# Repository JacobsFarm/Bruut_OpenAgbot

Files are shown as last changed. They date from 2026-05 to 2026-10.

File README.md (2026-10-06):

# Bruut_OpenAgbot
Project for making the Bruut_OpenAgbot 

Follow along the project on youtube: https://www.youtube.com/@opensource_agbot/videos
Visit the website for more information https://jacobsfarm.github.io/Bruut_openagbot_website/ 
Go for the implements to the special repo https://github.com/JacobsFarm/Bruut_OpenAgbot_Implements

newest configuration the 2WD: with AB line driving
DJI_0523
dasgewagergsdg

This repo contains all the code information and code for the Agbot bruut Project 
The first runs for the prototype wil be used code in Python, C++ and the front end bases on svelte
later the project wil immigrate to ROS 2 and Floxglove 

## openscad project
New cad designs after testing in the Field, stronger and more realistic designs and even more oppertunity for extensions

animation_drive_turn
animatie_ridderzuringfrees
animation_strip_ground_following

**4 wheeldrive designs** with 4 electric driven hubmotors
Schermafbeelding 2026-05-24 135653
Schermafbeelding 2026-05-24 135643
Schermafbeelding 2026-05-24 135613
Schermafbeelding 2026-05-24 135552

**2 wheeldrive designs** difference is 2 wheel casters in the back
Schermafbeelding 2026-05-24 223704
Schermafbeelding 2026-05-24 223727

## AB line driving
Schermafbeelding 2026-08-24 190629
DJI_0523

## Options 
making taskcards of the detection of diseases / birdnests or Sprayed weed
Schermafbeelding 2026-04-26 231133

## AB-line missions

Autonomous field work runs on AB lines. You measure two points with the RTK:
**A = the bottom-left corner** of the field and **B = the top-left corner**.
Together they set the direction and the length of the swaths.

Build the mission with a single script:

```bash
python Single_script_code/AB_mission_maker.py
```

Set the field name, the two points, the work width and the number of swaths at
the top of the script. It writes the mission into `data/ab_line.json` and draws
a preview: `ab_missie.jpg` (field sketch in metres), `ab_missie_gps.jpg` (same mission in lat/lon) and `ab_missie.html` (interactive satellite map)
so you can check the headlands before driving.

The script plans a **skip pass** order: on the way out it skips a swath every
time (0, 2, 4, 6) and on the way back it fills the gaps (7, 5, 3, 1). The side
step at almost every headland turn is then twice the work width, which is
exactly what a four-wheeler needs - a half circle of twice the minimum turning
radius fits. Only at the turning point of the pattern (6 -> 7) do two swaths sit
next to each other; there the robot drives an omega turn instead.

At the end of a swath the robot keeps going straight for `kopakker_extra_m`
(2 m by default) into the headland before it turns. The turn is built so that it
ends at exactly the same distance along the line as where it started, so after
the turn the robot has that same 2 m of straight run-in to settle dead straight
on the new line before the crop begins.

Pick the field in the web interface under **Landbouw** and press start.

> [!WARNING]
> **Disclaimer: use at your own risk**
> - This is an experimental prototype under active development, not a finished or certified product.
> - All software and designs are open source (AGPL-3.0) and provided **"as is"**, without warranty of any kind. The makers and contributors are not liable for any damage, injury or loss resulting from their use (see sections 15 and 16 of the license).
> - Autonomous machines can behave unexpectedly, for example by driving into a ditch or water. Always supervise the robot, test at low speed, use a physical emergency stop, an RC failsafe and a geofence, and keep people and animals at a safe distance.
> - You are responsible for complying with local laws and safety regulations. Do not use the robot on public roads.

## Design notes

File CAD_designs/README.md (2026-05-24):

# Bruut_OpenAgbot
Project for making the Bruut_OpenAgbot 

Gemini_Generated_Image_ldpsodldpsodldps(1)

## openscad project
Volume 2 ( redesign (better alignments and stronger realistic design  
Schermafbeelding 2026-05-24 135552
Schermafbeelding 2026-05-24 135643
Schermafbeelding 2026-05-24 135653


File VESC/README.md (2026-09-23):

# VESC instellen — Bruut OpenAgbot

Twee **VESC Classic 100V** sturen elk een **Quinder 8" 48V 550W naafmotor** aan,
gevoed uit een **EGO 56 V-accu**, aangestuurd door de Jetson over **CAN**.

| | |
|---|---|
| Motor | Quinder 8" 48V 550W · art. 10101025 · 2× |
| Controller | VESC Classic 100V · 2× |
| Accu | EGO 56 V, 5 Ah = **14S2P** · ~252 Wh |
| Vervangt | Quinder DC-controller 10301059 + Arduino/MCP4728-DAC |
| Aansturing | Jetson · CAN 500 kbit/s · ID 0 (links) en 1 (rechts) |
| Topsnelheid | 6 km/h = 3 900 ERPM · **nooit boven 7 km/h** |

Dit bestand is de **werkvolgorde en de instellingen**. De volledige onderbouwing —
waarom CAN en geen UART, hoe het thermisch model werkt, de vermogensbalans bij
remmen — staat in [README_DEV.md](README_DEV.md).

> De VESC Tool is gratis. Een kleine donatie aan het VESC-project helpt hen
> verder met de software waar jij op meelift.

---

## Voordat er spanning op staat

* **Wiel vrij van de grond.** Bok eronder, vóórdat de accu erop gaat.
* **Precharge.** XT90-S of voorlaadweerstand — dit board heeft flinke condensatoren.
* **Quinder-controller volledig los van de fasedraden**, maar **niet doorknippen**:
  hij is je terugvaloptie én je referentiemeting.
* **Fase = 2,5 mm², hall = 0,14 mm².** Blauw, groen en geel komen twee keer voor
  in de motorkabel. Verwissel je ze, dan blaas je de hall-sensoren op.
* **Nooit + en − verwisselen.** Dat sloopt de halls, en die zitten in een
  IP66-behuizing die je niet openmaakt.
* **Zekering 30 A**, en controleer de **DC**-waarde — auto-steekzekeringen zijn
  vaak op 32 V DC gespecificeerd en jij zit tot ~58 V.
* Eén board tegelijk via USB. CAN komt pas in stap 12.

**Begin met `Read Motor Configuration`.** Wat de VESC Tool zonder uitlezen toont
zijn defaults van een vreemd hardwareprofiel — dan bewerk je een configuratie die
nergens bestaat. Controleer je limieten ook **na elke firmware-flash**; een flash
kan ze resetten.

---

## De instellingen

Elk scherm afsluiten met **Write Motor Configuration**. De tool schrijft niets uit
zichzelf weg — en schrijft álle velden, ook die je niet aanraakte.

### Motor Settings → General

| Veld | Waarde | |
|---|---|---|
| Motor Type | **FOC** | Vol koppel vanaf stilstand, stil bij kruipsnelheid, bruikbare stroommeting |
| Invert Motor Direction | **False** | Beslis dit in stap 11. De motoren zitten gespiegeld, dus één board krijgt `True` |

Zet de vlag hier en niet in de software: dan draaien telemetrie, tacho en het
teken van de regenstroom mee. Wissel **geen fasedraden** — dat maakt de
uitgemeten halltabel ongeldig.

### Motor Settings → Sensors

| Veld | Waarde | |
|---|---|---|
| Sensor Port Mode | **Hall Sensors** | Ons hele bereik is 0–3 900 ERPM; de sensorloze waarnemer wordt pas ergens rond 1 000–2 000 ERPM betrouwbaar. Sensorloos betekent elke start op een helling blind |

Encoder- en Sin/Cos-velden ongemoeid laten: die worden niet gelezen.

### Motor Settings → Current

| Veld | Default | Waarde | |
|---|---|---|---|
| Motor Current Max | 60 A | **15 A** | Continu belastbaar is ~9 A. 15 i.p.v. 20 A scheelt 44 % warmte (I²) en kost 25 % piekkoppel |
| Motor Current Max Brake | −60 A | **−10 A** | Remmen belast dezelfde wikkeling, vaak ná een klim |
| Absolute Maximum Current | 150 A | **30 A** | Noodrem, geen regellimiet. 2× bedrijf, ruim onder wat 2,5 mm² aankan |
| Slow ABS Current Limit | False | **False** | Houdt die trip snel; True maakt er een trage softwarelimiet van |
| Battery Current Max | 99 A | **20 A** | Motorspec max output. Wordt in de praktijk nooit bereikt: de motorlimiet bindt eerder |
| Battery Current Max Regen | −60 A | **−3 A** | Zie *Remmen* hieronder — dit getal hangt aan de accu, niet aan de motor |

Overige velden (current scales, input current map, DRV8301) laten staan.

### Motor Settings → Voltage

| Veld | Default | Waarde | |
|---|---|---|---|
| Battery Voltage Cutoff Start | 10 V | **42,0 V** | Motorspec zegt 41 ±1 V, én het is 3,00 V/cel op 14S. Twee redeneringen, één antwoord |
| Battery Voltage Cutoff End | 8 V | **40,0 V** | Dit is de **enige** onderspanningsbeveiliging die er is — zie *De accu* |
| Battery Voltage Regen Cutoff Start | 1000 V | **56,0 V** | Vanaf hier bouwt de VESC de teruglevering zelf af. Het bijpassende snelheidsplafond in de software is nog niet gebouwd — zie README_DEV |
| Battery Voltage Regen Cutoff End | 1100 V | **57,5 V** | = gemiddeld 4,11 V/cel. Bewust laag: er is geen celbewaking die ingrijpt |
| Battery Filter Constant | 45 | *laten* | Niet scherper zetten: onder belasting zakt de spanning kort in, en zonder filter gaat je cutoff af op elke stroompiek |

### Motor Settings → RPM

| Veld | Default | Waarde | |
|---|---|---|---|
| Max ERPM | 100 000 | **3 900** | 6 km/h. Absoluut plafond 4 569 (7 km/h) — daar nooit overheen |
| Max ERPM Reverse | −100 000 | **−3 900** | Open punt: halveren naar −1 950 (3 km/h) is verdedigbaar op 500 kg |
| ERPM Limit Start | 80 % | *laten* | Knijpt vanaf 3 120 geleidelijk af i.p.v. tegen een muur |

### Motor Settings → Wattage

**Beide velden laten staan** (1 500 000 W = begrenzer uit). De stroomlimieten
begrenzen het vermogen al; een wattlimiet ernaast is een tweede begrenzer voor
dezelfde grootheid, die zich anders gaat gedragen naarmate het pak leegloopt.

### Motor Settings → Temperature

| Veld | Waarde | |
|---|---|---|
| Motor Temperature Sensor Type | **Disabled** | De Quinder-sensor is **geen thermistor**: hij geeft actief spanning af (~4,8 V koud, 1,09 V bij 105 °C, 0,68 V bij 110 °C). Tegen een 10k pull-up levert dat geen meting op |
| MOSFET Temp Cutoff | 85 / 100 °C *laten* | Echte sensor op het board. De enige thermische meting zonder aanname eronder |

Het paarse draadje gaat via een deler ÷2 naar **AD2**, waar een Lisp-script de
drempels bewaakt. Zolang dat script niet draait, is het thermisch model in
`motor_logic.py` je enige motorbescherming — en dat draait op berekende, nog niet
geijkte startwaarden.

### Motor Settings → BMS

**BMS Type → `Disabled`.** Dit scherm is voor een VESC-BMS die celspanningen over
CAN doorgeeft. Een EGO-pak spreekt dat protocol niet. Laat je het op *VESC BMS*
staan, dan staat er een begrenzer scherp die wacht op gegevens die nooit komen.

### Motor Settings → Advanced

| Veld | Default | Waarde | |
|---|---|---|---|
| **Maximum Input Voltage** | **57,0 V** | **65,0 V** | Een vol 14S-pak is 58,8 V. Op 57 V krijg je een `OVER_VOLTAGE`-fout zodra de accu vol van de lader komt — en een fout zet de motor in één klap uit |
| Maximum Duty Cycle | 95 % | *laten* | Niet naar 100 %: die marge heeft de eindtrap nodig om fasestroom te meten |
| Fault Stop Time | 500 ms | *laten* | **Niet** de CAN-timeout — die staat in App Settings en is toevallig ook 500 ms |
| Additional Faults | uit | **uit laten** | Zie hieronder |

> `57,0 V` is een 12S-default. Staat dat er ná `Read Motor Configuration` nog
> steeds, dan is het uitlezen niet gelukt. Op een echt 100 V-board hoort hier al
> 90 V of meer te staan — laat het dan staan.

**Waarom `Overspeed` uit blijft:** een fout zet de motor uit, en deze machine
heeft geen mechanische rem. Rolt hij een helling af en gaat daardoor over de
limiet, dan haalt die fout precies weg wat hem nog tegenhield. Runaway-detectie
zit in de software, waar de reactie een *gestuurde* actie kan zijn.

### Motor Settings → FOC · detectie

Halls aangesloten, wiel vrij, limieten hierboven al weggeschreven. Draai de
detectie en lees de uitkomst één keer goed:

* De zes middelste getallen van de halltabel horen **zes verschillende** waarden
  te zijn. Twee dezelfde = een sensor die niet schakelt.
* **0 en 7 horen er niet in te staan** — dat is alle drie laag of alle drie hoog:
  dode sensor, gebroken draad of geen voeding.
* Noteer R, L en flux linkage in het [Meetblad](#meetblad).

Klopt de tabel niet, dan is dat bedrading — niet iets wat je met een instelling
repareert.

### Motor Settings → PID Controllers

**Speed PID min ERPM → 150.** Standaard staat dit veel hoger; daarmee regelt hij
onder ~1,4 km/h niet.

### App Settings · per board

| Parameter | Links | Rechts | |
|---|---|---|---|
| VESC ID | **0** | **1** | Onderste byte van elk CAN-adres; moet uniek zijn |
| CAN Baud Rate | 500k | 500k | |
| CAN Status Message Mode | 1 – 5 | 1 – 5 | Levert eRPM, stroom, duty, temperaturen, tacho en `v_in` zonder pollen |
| CAN Status Rate | 50 Hz | 50 Hz | |
| Multiple VESCs Over CAN | **uit** | **uit** | Die functie spiegelt één gascommando naar alle VESC's — aan betekent: niet kunnen sturen |
| Timeout | 500 ms | 500 ms | **De belangrijkste failsafe** |
| Timeout Brake Current | 0 A | 0 A | Uitrollen bij verlies van commando, niet remmen op een onbekende situatie |
| App to Use | UART / CAN | UART / CAN | Niet ADC — dat houdt AD2 vrij voor het temperatuursignaal |

**De timeout is je beste beveiliging omdat hij niet van onze software afhangt.**
Stopt de Jetson met sturen, dan zetten beide VESC's zichzelf na 500 ms uit — ook
als deze codebase niet meer draait. Daarom zendt de regellus in
`vehicle_controller.py` onafgebroken op 50 Hz, ook als er niets verandert.

**Toon dat één keer aan:** laat een wiel draaien en trek de CAN-kabel eruit. Hij
hoort binnen een halve seconde uit te vallen.

---

## Remmen

**Er zit nergens een mechanische rem.** Wat de machine tegenhoudt is uitsluitend
wat de VESC elektrisch doet, en dat kan alleen als de accu de energie aanneemt.

Een regenlimiet is **geen kraan die stroom omleidt** — het is een randvoorwaarde
voor de regelaar. Mag er niets naar het pak, dan verlaagt de VESC de fasestroom:
hij remt minder hard. De energie wordt niet omgeleid, hij wordt niet onttrokken,
en de machine rolt door. Bij stilstand kun je wél vol houden (snelheid nul, dus
geen mechanisch vermogen — alles wordt warmte).

| Regen per VESC | Totaal | Houdt bij 6 km/h | Houdt bij 3 km/h |
|---|---|---|---|
| **−3 A** | 6 A · 312 W | **~4 %** | ~8 % |
| −5 A | 10 A · 520 W | ~6 % | ~13 % |
| −10 A | 20 A · 1 040 W | ~13 % | ~25 % |

Vuistregel bij 6 km/h: elke ampère teruglevering koopt ~0,6 % helling.

**Waarom −3 A en niet meer:** laadstroom hoort afgezet tegen het aantal cellen
*parallel*. Het 10 Ah-pak is 14S4P van 2,5 Ah-cellen (Samsung INR18650-25R,
4 A snellaadstroom), dus een 5 Ah-pak is **14S2P**. Met −3 A per VESC zit je op
3 A per cel; met −5 A op 5 A per cel, boven spec.

| Pak | Opbouw | Regen per VESC |
|---|---|---|
| 2,5 Ah | 14S1P | −1,5 A |
| **5,0 Ah** | **14S2P** | **−3 A** |
| 7,5 Ah | 14S3P | −4 A |
| 10 / 12 Ah | 14S4P | −5 A |

> **Een te lage regenlimiet maakt niets kapot.** De VESC maakt die stroom
> eenvoudigweg niet. De keuze voor een mechanische rem is een veiligheids- en
> functievraag, geen vraag over het beschermen van onderdelen.

**Waar het wél misgaat:** slepen of rollen met de controller uit. Dan regelt
niemand en komt de generatorspanning via de body-diodes hoe dan ook op de bus.
Met accu erop wordt die geklemd; zonder accu laden de condensatoren op tot niets
het meer tegenhoudt. **Sleep nooit met de hoofdschakelaar uit, en precharge ook
na een sleepbeurt.**

**En stilstaand een helling houden op stroom kookt de motor** — vol koppel, geen
luchtstroom. Daarvoor is de stall-detectie.

---

## De accu

Wat de teardowns en de DIY-gemeenschap over EGO 56 V-pakken melden, en wat het
voor ons betekent:

* **De plus- en minklem gaan rechtstreeks naar de cellenstring, om de elektronica
  heen.** De hoofdstroom loopt niet door de BMS.
* **Er zit geen afschakel-MOSFET in.** De BMS beveiligt door over de `D`-pin
  tegen het *gereedschap* te zeggen dat het moet uitschakelen — en een VESC is
  geen EGO-gereedschap.

| | Gevolg |
|---|---|
| Afkoppelen tijdens remmen | **Kan niet** — er is geen schakelaar om te openen |
| Overladen via regen | **Niemand vangt het af.** Geen cutoff, geen laadstroomlimiet, geen celbewaking |
| Onderspanning per cel | Niet beschermd. Onze 42,0 V is de enige grens |

Alles wat dit pak tijdens teruglevering beschermt is dus een instelling in onze
VESC. Daarom ligt de regenband bewust laag.

**Nog te meten:** wat een vol pak werkelijk aanwijst. EGO geeft 50,4 V nominaal
op en de cellen zijn 4,2 V-types, dus 58,8 V is de theoretische bovengrens — maar
de naam "56 V" volgt de conventie waarin het merkgetal 14 × 4,0 V is. Eén
multimetermeting na het laden beslist de hele taperband.

**En meet wat de stock-controller doet.** Die heeft op déze machine met dít pak
al geremd. Stroomtang om de plusdraad op een helling die hij nog houdt: meer dan
6 A betekent dat onze −3 A conservatief is.

---

## Bedrading

### Motor → VESC

Kabel 3 × 2,5 mm² + 8 × 0,14 mm², 200 mm — je hebt een verlengboom nodig.

| Draad | Ø | Functie | Naar |
|---|---|---|---|
| Blauw / Groen / Geel | 2,5 | Motorfase A / B / C | Fase-uitgangen |
| Rood / Zwart | 0,14 | Hall + / − | Sensorconnector +5V / GND |
| Blauw / Groen / Geel | 0,14 | Hall A / B / C | H1 / H2 / H3 |
| Wit | 0,14 | Toerentalpuls (6/omw) | **Niet aansluiten** — de VESC telt via de halls, tienmaal fijner |
| Paars | 0,14 | Temperatuursignaal | Via deler ÷2 → IO-connector AD2 |

De hall-volgorde is niet kritisch: de detectie meet de tabel uit.

```
IO-CONNECTOR                        SENSORCONNECTOR
paars (temp) ──[10k]──┬── AD2       rood  ── +5V
                      │             zwart ── GND
                    [10k]           blauw ── H1
                      │             groen ── H2
                      ├──[100nF]    geel  ── H3
                      └── GND
```

### CAN

JST-GH 4-polig: `1 = 5V uit`, `2 = CANH`, `3 = CANL`, `4 = GND`.

* **Verbind pin 1 niet tussen de twee VESC's.** Dat is bij allebei een *uitgang*.
  Tussen de boards lopen alleen CANH, CANL en GND.
* **Eén CAN-connector per board**, dus drie knopen betekent een T-split of een
  verdeelprintje — doorlussen kan niet.
* **120 Ω alleen aan de twee fysieke uiteinden.** Meet met de accu los tussen
  CANH en CANL: je hoort **~60 Ω** te zien. 40 Ω = drie terminators, 120 Ω = één.
* Twisted pair plus een aparte GND-draad. Vertrouw niet op het chassis, en houd
  de bundel weg bij de fasedraden.

**Aan de Jetson-kant: een geïsoleerde socketcan-adapter.** De productpagina moet
*SocketCAN*, *gs_usb* of *candleLight* noemen en hij moet als `can0` verschijnen
— bijvoorbeeld een InnoMaker USB2CAN (ISO1050) of CANable Pro. Een goedkope
CH340-UART-brug is **niet** bruikbaar: die verschijnt als `/dev/ttyUSB0` en kan
geen willekeurige 29-bits ID's sturen. Je hebt er **één** nodig, niet twee — CAN
is een bus.

```bash
ip link | grep can        # can0 -> goed
sudo ip link set can0 up type can bitrate 500000 restart-ms 100
candump can0              # statusframes van beide ID's op 50 Hz
```

Zonder `restart-ms` blijft de interface dood na één bus-off. `setup/can0.service`
doet dit bij elke boot.

---

## Rekenwaarden

Herbereken deze als je van band, tandwielkast, massa of accu wisselt.

| Grootheid | Waarde | Afleiding |
|---|---|---|
| Bandomtrek | 1,277 m | 16" buitenmaat × π |
| Poolparen · overbrenging | 10 · 5:1 | |
| **ERPM per wiel-RPM** | **× 50** | 5 × 10 |
| 6 km/h | 3 917 ERPM | afgerond naar 3 900 |
| 7 km/h — nooit hoger | 4 569 ERPM | grens DaviLot |
| Tellen per wielomwenteling | 300 | odometrie: 4,26 mm per tel |
| Continu belastbaar | 9,0 A · 75 RPM | ≈ 5,7 km/h |
| Massa (aslast) | 500 kg | motorspec |
| Accu vol (theoretisch) | 58,8 V | 14S × 4,2 V — **meet dit na** |

---

## Beveiligingslagen

| # | Waar | Wat |
|---|---|---|
| 1 | VESC | Motor Current Max 15 A — voorkomt de oorzaak |
| 2 | Software | Stall-detectie op stroom en toerental |
| 3 | Software | Thermisch model op gemeten stroom (ongeijkt) |
| 4 | VESC | **Timeout 500 ms** — werkt ook als onze software dood is |
| 5 | Hardware | Zekering 30 A DC |
| 6 | VESC | Lisp-script op AD2 met de echte motorsensor |

---

## Meetblad

Invullen tijdens het in bedrijf stellen. Dit is de verantwoording van wat er
werkelijk in de boards staat.

| | Links (ID 0) | Rechts (ID 1) |
|---|---|---|
| Datum · serienummer · firmware | | |
| Halltabel (8 getallen) | | |
| Motor R (mΩ) · L (µH) · flux (mWb) | | |
| Invert Motor Direction | | |
| Vol commando → gemeten ERPM | | |
| Maximum Input Voltage zoals uitgelezen | | |
| Paarse draad koud gemeten (V) | | |
| Timeout aangetoond (datum) | | |
| Geëxporteerd configbestand | | |

Eenmalig, niet per board:

| | Waarde |
|---|---|
| Pakspanning vol, direct na laden | |
| Nemen de klemmen stroom aan? (labvoeding ~0,5 A) | |
| Regenstroom stock Quinder-controller (stroomtang) | |
| Neemt het pak −3 A regen aan? | |

---

## Tot slot

**Schrijf `vesc_mcconf_openagbot_bruut_500_watt_hubmotor.xml` niet naar een
board.** Dat is het oude profiel van ánder materiaal; de motorparameters zijn
niet van deze motor. De werkwijze is andersom: uitlezen, limieten invoeren,
detectie draaien, en het resultaat **exporteren naar deze map**. Dát wordt het
echte configbestand.

Verdieping — waarom CAN en geen UART, waarom geen Arduino in het stuurpad, de
vermogensbalans bij remmen, het Lisp-script, de openstaande vragen:
[README_DEV.md](README_DEV.md).

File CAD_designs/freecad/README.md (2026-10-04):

# Bruut OpenAgbot - FreeCAD model

FreeCAD 1.1 versie van het ontwerp: 2 vaste hubmotorwielen achter, 2 sturende hubmotorwielen voor met elk een
stappenmotor (NEMA34 + 5:1 planeetkast) erboven. Gebouwd uit de OpenSCAD-bestanden, de foto's in `Design real life/`
en de stappenmotorplaat `parts/PLOATIE 2.STP`.

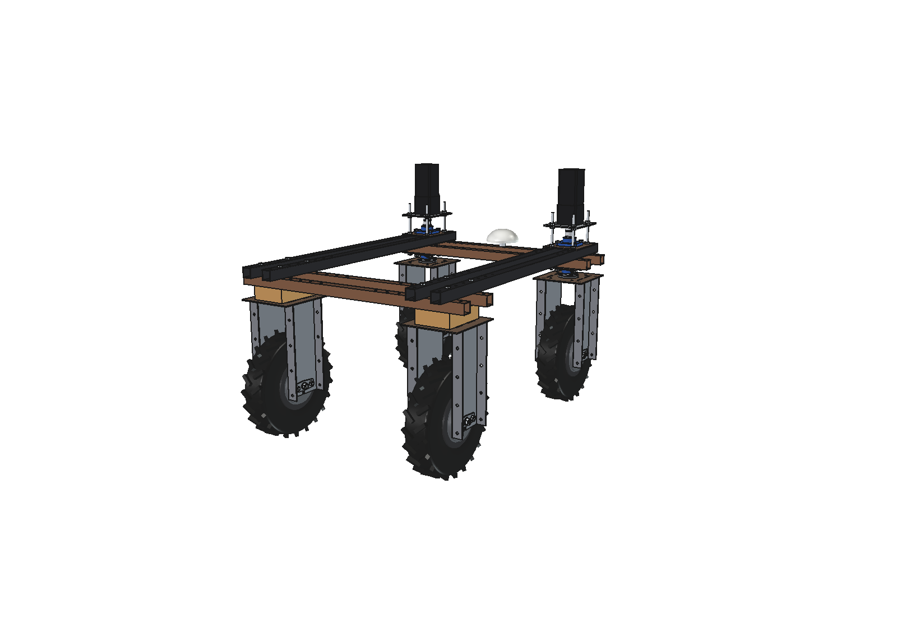
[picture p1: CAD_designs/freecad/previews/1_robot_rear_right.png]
achteraanzicht

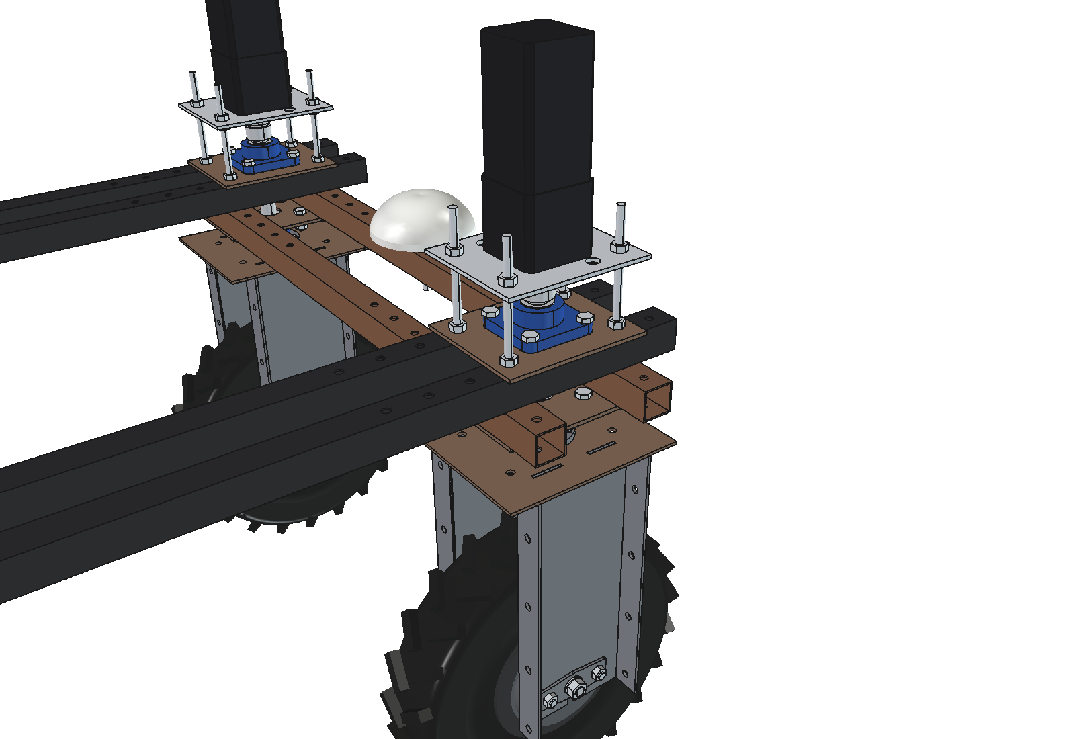
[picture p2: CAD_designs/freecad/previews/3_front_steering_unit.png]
stuurkop


## Bestanden

| Bestand | Inhoud |
| --- | --- |
| `Bruut_OpenAgbot.FCStd` | het model (openen in FreeCAD) |
| `agbot_params.py` | alle maten, zelfde namen en waarden als `config/parameters.scad`, plus de nieuwe stuurparameters |
| `agbot_parts.py` | een functie per fysiek onderdeel (zoals `parts/*.scad`) |
| `build_agbot.py` | zet de onderdelen in de boomstructuur, kleurt ze en slaat op |
| `run_in_freecad.py` | start-macro: open in FreeCAD en voer uit (F6), dan wordt het model opnieuw gegenereerd |
| `animate_agbot.py` | animatie rijden en draaien: kinematica, live afspelen in FreeCAD, frames renderen |
| `make_gif.py` | zet de gerenderde frames om naar een GIF (Pillow) |
| `previews/` | afbeeldingen (isometrisch, bovenaanzicht, zijaanzicht, achteraanzicht, stuurkop) en `animation_drive_turn.gif` |

Opnieuw genereren overschrijft het open document `Bruut_OpenAgbot` en `Bruut_OpenAgbot.FCStd`.
Pas maten aan in `agbot_params.py`, nooit in het FCStd-bestand zelf (die onderdelen zijn niet parametrisch).

## Assen

x = rechts, y = rijrichting (voor = +y), z = omhoog, grond = z 0. Wielmiddens op x = ±375, y = ±500, as op z = 215.
In FreeCAD's "Front"-weergave kijk je dus naar de achterkant van de robot; "Rear" toont de voorkant.

## Boomstructuur

```
Bruut_OpenAgbot_robot
  chassis_frame                  4 onderste balken (chassis_beam_1), 4 bovenste balken (chassis_beam_2), GNSS-antenne
  wheel_unit_rear_left / right   hubmotorwiel, wielbeugel, houten blok, boutwerk
  wheel_unit_front_left / right  stuurkop: lagerplaten, 2 flenslagers, stappenmotorplaat, stappenmotor, draadstangen
    steered_part_front_*         alles dat meedraait met het stuur: wiel, beugel, stuuras, koppeling
  optional_frame_cover_NOT_ON_PHOTOS   main_base_plate, upright_wall, protection_cover (verborgen)
```

## Sturen

Draai `steered_part_front_left` / `steered_part_front_right` (Placement, rotatie om z; + = naar links), of in de
Python-console:

```python
import build_agbot
build_agbot.set_steering(30, 22)
```

Binnenwiel scherper dan buitenwiel (Ackermann), zie ook `setup/information/steppermotor_information.json`.

## Animatie

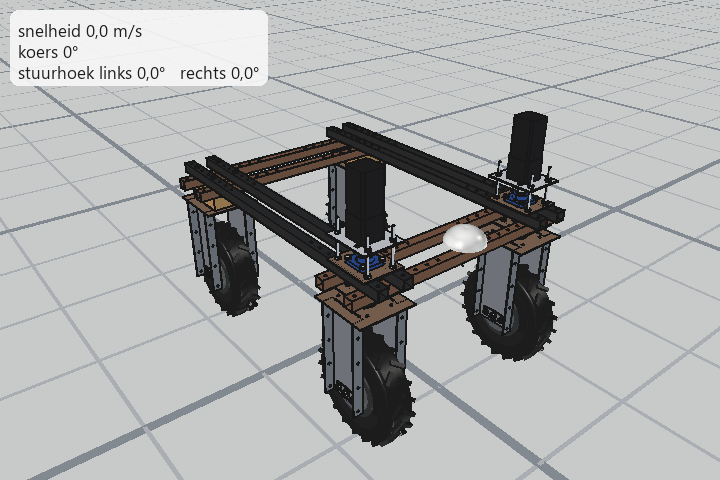
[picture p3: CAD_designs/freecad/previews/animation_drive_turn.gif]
rijden en draaien


De robot rijdt 1,2 m rechtuit (0 naar 1 m/s), stuurt naar links, draait 90° en rijdt weer rechtuit tot stilstand.
Kinematica: fietsmodel op het midden van de achteras. Elk voorwiel krijgt zijn eigen stuurhoek (Ackermann: bij 25°
middenhoek staat het binnenwiel op 29,5° en het buitenwiel op 21,6°, draaicirkel 2,1 m), alle wielen rollen zonder
slip af en de stuurmotoren draaien met 35°/s. Snelheid, hoeken en afstanden staan bovenaan `animate_agbot.py`.

Live afspelen in FreeCAD (het model `Bruut_OpenAgbot` moet open staan, de camera volgt de robot):

```python
import animate_agbot
animate_agbot.play()
animate_agbot.stop()
```

De GIF opnieuw maken (frames renderen in FreeCAD, daarna in een gewone terminal):

```python
animate_agbot.render_all(r"C:\temp\frames")
```

```
python make_gif.py C:\temp\frames previews\animation_drive_turn.gif 15
```

## Wat komt waar vandaan

**Exact uit OpenSCAD** (volume en afmetingen vergeleken met een OpenSCAD-STL-export: verschil < 0,01 %):
`bracket_top_plate`, `bracket_side_plate` (gebogen uitvoering), `axle_bracket`, `chassis_beam_1`, `chassis_beam_2`,
`main_base_plate`, `upright_wall`, `protection_cover`, positie van de wielen en de balken.
`PLOATIE 2` is parametrisch nagebouwd en heeft hetzelfde volume als het STEP-bestand (131 249,2 mm3).

**Afgeleid uit de foto's, maten geschat (aanpassen in `agbot_params.py`):**
- stuurkop: draaipuntflens op de top plate (4x M8, 50 x 50), stuuras O25, twee flenslagers (blauw, UCF205-maten) in
  platen onder en boven het frame, koppeling, 4 draadstangen M10 op het 150 x 100 patroon;
- stappenmotor + planeetkast (90 x 90 x 85 en 86 x 86 x 150), top van de motor op 1032 mm;
- `steering_gap` = 55 mm tussen top plate en onderste balken; achter vult een houten blok die ruimte;
- positie van de GNSS-antenne: midden, op de voorste dwarsbalk.

**Vervangers** (de STL's `hubmotor_quinder*.stl` en `tire_4.8_4.00-8.stl` staan niet in de repo): band 430 x 100 met
tractorprofiel, velg 8", motorhuis O160 x 140. Alle vier de wielen zijn gelijk, ook de voorste (op de foto's zitten
daar nog andere banden).

**Niet gemodelleerd:** kabels, trekhaak, label op de motor, afschuiningen op moeren.

## Aandachtspunten

- De optionele frame-onderdelen (uit `chassis_frame_asm.scad`) staan niet op de foto's en botsen met de rechter
  stuurkop (stappenmotor op x = 375, y = 500). Daarom verborgen.
- In OpenSCAD liggen de onderste balken 2 mm boven de top plate (`bracket_top_z` als plaatmidden). Hier liggen ze
  tegen de plaat of het houten blok.
- Controle op interferentie: geen overlap tussen de 80 zichtbare onderdelen.

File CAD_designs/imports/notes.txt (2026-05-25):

In this directory can you place yout STL files for importing them into your designs

The used STL models can be retrieved from the importer of yout hubmotor, i use Quinder 48v hubmotors
The used STL models for the casterwheels are from a wheelbarrow wheel and can be downloaded from the next link https://grabcad.com/library/wheelbarrow-wheel-4-80-4-00-8-1

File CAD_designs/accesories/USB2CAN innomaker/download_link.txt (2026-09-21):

To download een ready to use Innomaker USB2CAN module case.
  
https://makerworld.com/en/models/28738-innomaker-usb2can-module-case?utm_source=gemini#profileId-2465581

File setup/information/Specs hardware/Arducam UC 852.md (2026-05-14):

Overview

Arducam B0385 is a new member of Arducam's USB camera family. It's a 1MP, based on the 1/4" color global shutter OV9782 image sensor, UVC compliant, low distortion USB 2.0 camera.

No longer be anxious about installing the driver! The native UVC drivers of Windows, Linux and Mac shall be compatible with this camera so that it does not require extra drivers to be installed.

The global shutter sensor's excellent low-light sensitivity makes it shoot crisp sharp and accurate complete color images even for high-speed moving objects.

Features

    Based on 1MP color global shutter sensor OV9782, assembled with a 70°(H) low distortion M12 lens with 650nm IR filter, sensitive to Visible Light.
    Global Shutter: Shoot high-speed moving objects in crisp sharp images. Avoid the rolling artifacts to get a much more accurate complete picture than the rolling shutter cameras. Reserved external trigger ports, support trigger via external signal.
    Resolution: 1MP 1280H x 800V; Frame Rates: MJPG 100fps@1280 x 800/720p/800 x 600/640 x 480/320 x 240; YUY2 10fps@1280 x 800/1280 x 720.
    Plug&Play: UVC-compliant, just connect the camera to a PC computer, laptop, Android device, or Raspberry Pi with the USB cable without extra drivers to be installed.
    Applications: The sensor's excellent low-light sensitivity and the low distortion lens allow it to perform better in any application that needs gesture and eye tracking, iris and physiognomy recognition, depth, and motion detection.

Applications

Iris and face recognition

Astrophotography

Gesture and eye tracking

Depth and motion detection

Home video surveillance system

......
Specs

Camera

- Sensor: 1/4” OV9782

- Resolution: 1MP 1280 x 800

- Data Format: MJPG/YUY2

- Frame Rate: MJPG 100fps@1280 x 800/720p/800 x 600/640 x 480/320 x 240; YUY2 10fps@1280 x 800/1280 x 720.

Lens

- Field of View (FOV): 70 degrees (H)

- Lens Mount: M12

- IR Sensitivity: IR filter, sensitive to Visible Light

- Focusing Range: 3.3ft (1M) to infinity

Functionality and Compatibility

- Adjustable parameter: Exposure/ White Balance

- System Compatibility: Windows, Linux, Mac, and OS with UVC driver

Power

- Power Supply: USB powered 5V

- Working Current: MAX 200mA

Physical

- Operating Temp.: -4°F~158°F (-20°C~+70°C).

- Dimension: 38mmx38mm (Hole pitch compatible with 34mmx34mm, 28x28mm)

- Cable Length: 3.3ft (1M)

1.1 Supported resolutions and frame rates¶
MJPG    1280×800@100fps
MJPG    800×600@100fps
MJPG    640×480@100fps
MJPG    320×240@100fps
YUV2    1280×800@10fps
YUV2    1280×720@10fps

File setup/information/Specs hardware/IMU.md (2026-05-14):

Virtual reality is populair, maar je zou geen honderden dollars moeten uitgeven om de technologie erachter te krijgen. Gelukkig is dit waar de VR IMU Breakout binnenkomt. De kern is CEVA's BNO086, een gecombineerd triaxiale versnellingsmeter/gyroscoop/magnetometer-pakketsysteem (SiP) in 32-bits ARM © Cortex™M0 +. De BNO086 Inertial Measurement Unit (IMU) produceert nauwkeurige rotatievectorkoppen, ideaal voor VR-en andere koerstoepassingen, met een statische rotatiefout van 2 graden of minder. De VR IMU is precies waar we op hebben gewacht; Alle sensorgegevens worden samengevoegd en gecorrigeerd tot zinvolle, nauwkeurige IMU-informatie. Het is perfect voor elk project dat richting of beweging moet voelen.

Het IMU-splitbord wordt ook geleverd met twee I2C Qwiic-connectoren om de verbinding met het miniatuur QFN-pakket iets gemakkelijker te maken. Het maakt deel uit van het Qwiic-verbindingssysteem, dus u hoeft niet te lassen om erachter te komen hoe de dingen zijn georiënteerd. Als u echter liever een breadboard gebruikt, hebben we nog steeds 0,1 "uit elkaar geplaatste pinnen.

De BNO080 is ontworpen om te worden gebruikt in Android-telefoons en kan alle berekeningen aan die nodig zijn voor een virtual reality-bril met alleen de telefoon. Voor BNO080 EOL biedt CEVA een plug-in alternatief voor BNO086 met verbeterde functies (14-bits accelerometerfusie, minder inactief vermogen en interactieve kalibratie). De sensor is zeer krachtig en wordt geleverd met een complexe interface. Dankzij de jumper op het bord kun je kiezen tussen twee verschillende I2C-adressen. Niettemin, als I2C niet uw favoriete communicatieoptie is, kunnen de sensoren communiceren via SPI en UART! We hebben ook een I2C-based bibliotheek geschreven die rotatievectoren biedt (de metingen die de meeste mensen van een IMU willen), versnelling, gyroscoop-en magnetometermetingen, staptellingen, en activiteitsclassifiers (zoals fietsen).

Het is een ecosysteem van I2C-sensoren, actuatoren, schilden en kabels die prototyping sneller en minder foutgevoelig maken. Alle QWIIC-compatibele kaarten gebruiken de gemeenschappelijke 1mm pitch, 4-pins JST-connector. Dit vermindert de vereiste PCB-ruimte, en de gepolariseerde verbinding betekent dat u het niet verkeerd kunt ophangen.

Bedrijfsspanning

2.4v tot 3.6v

Meestal 3,3 V via Qwiic-kabel

I2C (standaard): tot 400kHz

SPI: tot 3MHz

UART: 3 mbps

Rotatievector

Dynamische fout: 3,5 °

Statische fout: 2.0 °

Spelrotatie vector

Dynamische fout: 2,5 °

Statische fout: 1,5 °

Dynamische cursusdrift: 0,5 °/ min

Geomagnetische rotatie vector

Dynamische rotatiefout: 4,5 °

Statische rotatiefout: 3,0 °

Zwaartekracht Hoekfout: 1,5 °

Lineaire versnellingsnauwkeurigheid: 0,35 m/s2

Accelerometer nauwkeurigheid: 0,3 m/s2

Nauwkeurigheid gyroscoop: 3.1 °/ s

Magnetometer nauwkeurigheid: 1.4 & micro;T

2 Qwiic-verbindingspoorten

I2C adres: 0x4B (standaard), 0x4A

I2C pull-up weerstand (2.2kΩ)

Vermogen LED

Springschot

Vermogen LED

I2C pull-up weerstand

Adreselectie

Protocol selectie 0

Protocol optie 1

Bordgrootte: 1.0in. X 1.2. (25,4mm x 30,48mm)

Gewicht: 3g.

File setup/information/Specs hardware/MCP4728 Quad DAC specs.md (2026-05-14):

The MCP4728 is a compact module featuring four 12-bit Digital-to-Analog Converters (DACs), ideal for precise voltage setting requirements. This module is compatible with STEMMA QT and Qwiic connectors for easy "plug-and-play" integration via I2C.

## Key Features

* **Quad 12-bit Outputs:** Four independent buffered voltage output DACs.
* **Non-Volatile Memory (EEPROM):** Ability to store DAC settings and I2C address bits in internal EEPROM. Saved settings are automatically loaded as defaults upon power-up.
* **Flexible Reference Voltage:** Choose between the input supply voltage (VCC) or an internal reference of 2.048V.
* **Adjustable Gain:** When using the internal reference, you can select 1X or 2X gain.
* **Fast Response:** Typical settling time of 6 μs.
* **I2C Interface:** Fully controllable via I2C with a default address of `0x60`.

## Technical Specifications

| Feature | Specification |
| :--- | :--- |
| **Resolution** | 12-bit  |
| **Operating Voltage** | 2.7 V to 5.5 V  |
| **Settling Time** | 6 μs (typical) |
| **Differential Non-Linearity (DNL)** | ±0.2 LSB (typical) |
| **Default I2C Address** | 0x60  |

## Voltage Output Ranges

The output voltage range depends on the selected reference voltage (Vref) and gain settings:

* **Internal VREF (2.048V):**
    * **Gain = 1:** 0.000V to 2.048V[.
    * **Gain = 2:** 0.000V to 4.096V (Ideal for ~5V applications).
* **External VREF (VDD/VCC):**
    * 0.000V to VDD (Allows matching the input voltage range, e.g., 3.3V or 5V)

## Pinout Overview

The module features several connection points for integration:
* **VCC:** Power supply (2.7V - 5.5V).
* **GND:** Ground.
* **SCL/SDA:** I2C Clock and Data lines.
* **VA, VB, VC, VD:** The four DAC output channels.
* **RDY:** Ready pin.
* **LDAC:** Latch DAC Synchronization pin.
"""

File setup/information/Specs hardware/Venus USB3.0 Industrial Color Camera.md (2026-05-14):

{
  "product": {
    "name": "Venus USB3.0 Industrial Color Camera",
    "part_number": "VEN-161-61U3C-M01",
    "manufacturer": "Daheng Imaging",
    "description": "Compact industrial USB3 Vision camera with Sony IMX296 global shutter sensor."
  },
  "housing_options": [
    {
      "model": "VEN-161-61U3C-M06",
      "housing": "No housing",
      "dimensions_mm": "32.5x32.5x8.1",
      "weight_g": 7
    },
    {
      "model": "VEN-161-61U3C-M05",
      "housing": "M12",
      "dimensions_mm": "35x35x15.1",
      "weight_g": 32
    },
    {
      "model": "VEN-161-61U3C-M01",
      "housing": "CS-mount",
      "dimensions_mm": "35x35x15.8",
      "weight_g": 31
    },
    {
      "model": "VEN-161-61U3C-M01 + 5mm extension ring",
      "housing": "C-Mount",
      "dimensions_mm": "35x35x20.8",
      "weight_g": 34
    }
  ],
  "lens_mount_options": {
    "supported_mounts": ["M12", "CS-mount", "C-Mount"],
    "notes": "M12 lenses can be used directly with the M12 version or with the CS-mount version using a C-to-M12 adapter."
  },
  "specifications": {
    "interface": "USB3 Vision",
    "resolution": {
      "width": 1440,
      "height": 1080
    },
    "megapixel": 2,
    "frame_rate_fps": 61,
    "sensor": {
      "model": "IMX296",
      "size": "1/2.9\"",
      "pixel_size_um": 3.45,
      "type": "Color",
      "shutter_type": "Global Shutter"
    },
    "shutter_time": {
      "min": "52us",
      "max": "1s"
    },
    "adc_bit_depth": 10,
    "pixel_bit_depth": [8, 10],
    "digital_gain_db": {
      "min": 0,
      "max": 24
    },
    "pixel_data_format": [
      "Bayer RG8",
      "Bayer RG10"
    ],
    "synchronization": [
      "Hardware trigger",
      "Software trigger"
    ],
    "io": {
      "input": 1,
      "gpio": 1
    },
    "operating_conditions": {
      "temperature_c": {
        "min": 0,
        "max": 45
      },
      "humidity_percent": {
        "min": 10,
        "max": 80
      }
    },
    "mount": ["S", "C"],
    "dimensions_mm": {
      "cs_m12": "35x35x15.2",
      "no_housing": "32.5x32.5x8.1"
    },
    "sdk_support": [
      "Windows",
      "Linux",
      "Android"
    ],
    "power_consumption": "<2.7W@5V",
    "weight_g": 32,
    "certifications": [
      "RoHS",
      "CE",
      "FCC",
      "USB3 Vision",
      "GenICam"
    ]
  },
  "industrial_color_camera_info": {
    "technology": "Bayer pattern",
    "advantages": [
      "Excellent image quality",
      "Larger and more light-sensitive pixels than webcams and security cameras"
    ],
    "limitations": [
      "Less sharp than monochrome cameras",
      "Lower light sensitivity due to RGB filters"
    ],
    "light_sensitivity_compensation": [
      "Increase ambient light",
      "Increase gain",
      "Increase shutter speed/exposure time",
      "Use a more light-sensitive sensor",
      "Use a more light-sensitive lens"
    ]
  },
  "warranty_and_lifecycle": {
    "annual_production": 100000,
    "certification": "TÜV Rheinland",
    "warranty_years": 3,
    "minimum_product_lifecycle_years": 7
  }
}

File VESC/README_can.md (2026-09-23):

# CAN wiring: Innomaker USB2CAN → VESC Classic 100V

Innomaker USB2CAN Module (bare board, DB9 male, micro-USB) on a Jetson, talking to a VESC Classic 100V over CAN at 500 kbit/s.

> **Never connect Pin 1 to 5 volt on the VSEC, its a 5 V output on both connectors.** The Innomaker is USB-powered, the VESC is battery-powered. Linking those two pins puts two supplies against each other, will blow up the controller and computer.

## Connect these 3 wires

```text
INNOMAKER DB9 (male)         VESC CLASSIC  CAN, 4-pin JST-GH 1.25 mm

pin 7  CAN_H   ───────────── pin 2  CANH    ┐ twisted pair
pin 2  CAN_L   ───────────── pin 3  CANL    ┘
pin 3  CAN_GND ───────────── pin 4  GND

pin 1  5V      ─ leave open ─ pin 1  +5V
DB9 pins 4, 5, 6, 8, 9: NC
```
Innomaker USB2CAN diagram

| Innomaker DB9 | Function | VESC CAN | Function |
|---|---|---|---|
| pin 7 | CAN_H, dominant high | pin 2 | CANH, ±60 V |
| pin 2 | CAN_L, dominant low | pin 3 | CANL, ±60 V |
| pin 3 | CAN_GND | pin 4 | GND, 1 A |
| pin 1 | 5 V out — only live if R9 is fitted | pin 1 | +5 V out, 1 A — **do not connect** |

- **Run CAN_H and CAN_L as a twisted pair**, roughly one turn per 2 cm.
- **The ground wire is not optional.** The Innomaker's transceiver is isolated (ISO1050); without CAN_GND it has no reference against the VESC and you get random error frames.
- Keep the CAN cable away from the phase wires — crossing at right angles is fine, running parallel is not. Alongside the motor, use shielded cable and ground the shield at one end only.
- Wire colours are free; nothing in the VESC depends on them.

## No open end

A CAN bus is a straight line with 120 Ω between CAN_H and CAN_L at **each** end. A wire left dangling reflects the signal and produces bit errors as soon as speed or length goes up.

Adding more VESCs later: daisy-chain wheel to wheel, stubs under 30 cm, and only the **two outermost** nodes get a resistor. With the Jetson at one end, the last VESC in the chain is the other.

## Termination

| Side | What to do |
|---|---|
| Innomaker USB2CAN Module | 120 Ω is on the board. Fit the jumper next to the DB9 — manual p. 11, *Enable 120 Ohm Resistor*. It usually ships disabled. |
| VESC Classic 100V | No termination on the board (not in the datasheet, confirmed by measurement). Solder a plain 120 Ω ¼ W across pins 2 and 3 of the JST-GH connector, or use a T-splitter with a resistor. |

Measure across CAN_H and CAN_L with the battery disconnected and USB unplugged:

| Reading | Meaning |
|---|---|
| open / very high | no termination at all |
| ≈ 120 Ω | one end terminated, the other still missing |
| ≈ 60 Ω | both ends terminated — this is what you want |

Also check CAN_H→GND and CAN_L→GND: both must be high impedance. If not, there's a solder bridge in the DB9.

## Bring it up on the Jetson

The module is a gs_usb SocketCAN device. VESC defaults to 500 kbit/s.

**On the Jetson Orin Nano (JetPack 6) the adapter is `can1`, not `can0`.** `can0` is the Orin's own CAN controller (mttcan). JetPack 6 also ships without `gs_usb`, so the driver is built with DKMS. The full steps are in [setup/information/innomaker_usb2can_jetson_setup.json](../setup/information/innomaker_usb2can_jetson_setup.json). The backend uses `vesc.can_channel` = `can1` from `data/config.json`.

```bash
sudo ip link set can1 down
sudo ip link set can1 type can bitrate 500000 loopback off
sudo ip link set can1 up
candump can1
```

`restart-ms` is not supported by gs_usb — `ip link set can1 up` fails with *"Device doesn't support restart from Bus Off"* if you pass it. After a bus-off, take the interface down and up again with the commands above.

## VESC Tool

*App Settings → General*:

| Setting | Value |
|---|---|
| CAN Baud Rate | `CAN_BAUD_500K` |
| CAN Mode | `VESC` |
| VESC ID | `1`, `2`, `3`, `4` — unique per controller |
| Can Status Rate 1 | `50` Hz, tick **Status 1** |
| Can Status Rate 2 | `5` Hz, tick **Status 4** and **Status 5** |

Status 1 at 50 Hz is the control loop; the rest belongs on the slow group. Four VESCs × 5 messages × 50 Hz is a quarter of the bus; Status 1 fast and the rest at 5 Hz is about 6%.

> **Write with ↑A, not ↑M.** VESC Tool keeps motor and app configuration separate, each with its own toolbar buttons. Writing App Settings with the motor-config button (↑M) silently discards them — the screen keeps showing your ticks while the controller never received them. Verify with ↓A: if the boxes survive a read-back, it landed.

## What comes over the bus

Extended IDs, built as `command << 8 | VESC ID`. For VESC ID 1:

| ID | Command | Contents |
|---|---|---|
| `0x901` | 9, STATUS | eRPM, motor current, duty — 50 Hz |
| `0x1001` | 16, STATUS_4 | temperatures, motor current |
| `0x1B01` | 27, STATUS_5 | input voltage, tacho |
| `0x3901` | 57, NOTIFY_BOOT | payload is the ASCII hardware name, sent once at power-up |

Status 1, all big-endian:

| Bytes | Value |
|---|---|
| 0–3 | eRPM, int32 |
| 4–5 | motor current, int16, ÷10 → A |
| 6–7 | duty cycle, int16, ÷1000 → fraction |

The Quinder has 20 poles = 10 pole pairs, so wheel RPM = eRPM ÷ 10. At standstill expect `00 00 00 00 00 00 FF FC`: zero rpm, zero current, −0.4% duty of noise around zero.

A useful check that does not depend on any status setting — ping controller 1 and watch for a reply:

```bash
cansend can0 00001101#00
```

## Troubleshooting

| Symptom | Cause |
|---|---|
| Rising `bus-errors` | missing ground wire, CAN_H/CAN_L swapped, or termination |
| `state BUS-OFF` / `ERROR-PASSIVE` | bitrate mismatch between the two ends |
| Silence, all counters zero | the VESC is not sending — Status boxes not ticked, or written with ↑M |
| A single frame at power-up, then nothing | NOTIFY_BOOT works, so the link is fine; it is the status config |

Check with `ip -details -statistics link show can0`. Note that a `cansend` on a bus with no second node **always** fails: nobody acknowledges the frame, the TX error counter climbs and the interface goes bus-off. That is CAN working as designed, not a broken adapter. Use `loopback on` to test the adapter by itself.

## Cable build

The module has a DB9 male, so you need a female solder-cup connector. For the VESC side, cut a ready-made VESC CAN lead in half: it already has crimped 1.25 mm JST-GH contacts, which are hard to crimp well by hand.

---

Sources: Innomaker USB2CAN Device UserManual v2.0 §4.1 (pinout, 120 Ω jumper); VESC Classic 100V datasheet rev. April 2026, table 2; ISO 11898-2:2016.

Full Dutch version with diagram: [can_vesc_bedrading.html](can_vesc_bedrading.html)

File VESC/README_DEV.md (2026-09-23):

# Aandrijving: twee VESC's op CAN

De twee hubmotoren achterop lopen sinds september 2026 op twee **VESC Classic
100V** controllers in plaats van op de Quinder DC-controller (art. 10301059).
De Jetson praat er rechtstreeks mee over **CAN**. De Arduino is daarmee uit het
aandrijfpad verdwenen; hij stuurt alleen nog de twee stappenmotoren van de
voorwielen.

| | |
|---|---|
| Motor | Quinder 8" 48V 550W · art. 10101025 |
| Controller | VESC Classic 100V, twee stuks |
| Vervangt | Quinder DC-controller 10301059 + Arduino/MCP4728-DAC |
| Aansturing | Jetson · CAN 500 kbit/s · 2 × VESC |

Bron van alle getallen hieronder: `CD-Quinder HUB motor specifications 2024-1`,
de VESC Classic 100V datasheet, en eigen metingen aan de stock-controller en de
EGO-accu (12 sep 2026).

---

## Waarom weg van de DAC

De oude keten was: Python → USB-serieel → Arduino → MCP4728 → een spanning van
0,77–3,4 V op de gashendel-ingang van de Quinder-controller. Die keten kon drie
dingen niet:

* **Terugmelden.** Er kwam geen enkel getal terug. Snelheid was een spanning
  waarvan we aannamen dat er een snelheid uit kwam.
* **Achteruit en remmen.** De gashendel-ingang kent alleen vooruit.
* **Beveiligen.** Zonder stroom- en toerentalmeting is stall-detectie onmogelijk.

Met de VESC's is snelheid een gevraagde eRPM die de controller zelf vasthoudt,
komt er op 50 Hz telemetrie terug (toerental, stroom, temperatuur, accuspanning,
tacho) en zijn achteruit en remmen gewone commando's.

---

## Bus en adressering

```
Jetson ──CAN──┬── VESC links  (ID 0)
              └── VESC rechts (ID 1)     500 kbit/s
```

Waarom beide controllers rechtstreeks aan de bus, en niet UART naar de ene en
CAN doorlussen naar de andere: bij doorlussen wordt de eerste VESC een single
point of failure voor het rechterwiel, en moet je telemetrie van de tweede gaan
pollen. USB is alleen voor de werkbank (VESC Tool) — in het veld her-enumereert
die bij elke spanningsdip.

### Wat je online vindt: de F1TENTH-driver

Zoek je op "VESC ROS", dan kom je uit bij de [F1TENTH vesc-repo](https://github.com/f1tenth/vesc)
en bij adviezen om gewoon een USB- of UART-kabel te trekken. Dat klopt — voor
een F1TENTH-auto. Die heeft **één** VESC en een stuurservo, en `vesc_ackermann`
vertaalt precies dat: één motorsnelheid plus één servostand.

Bruut is een ander voertuig: **twee** aangedreven wielen die onafhankelijk moeten
kunnen draaien, plus twee stuurstappenmotoren op een Arduino. Daarmee vervalt
zowel `vesc_ackermann` (verkeerde voertuigvorm) als de USB-aanname (`vesc_driver`
praat met één seriële poort per node, dus twee VESC's is twee kabels en twee
`/dev/ttyACM*`-nummers die bij elke boot kunnen wisselen).

Gaat dit project later naar ROS 2, dan is `vesc_msgs` een nuttige referentie voor
de berichtvorm, maar de aansturing hoort dan op `ros2_socketcan` te zitten — niet
op de seriële driver.

### App Settings per controller (VESC Tool)

| Parameter | Links | Rechts | Waarom |
|---|---|---|---|
| VESC ID | 0 | 1 | Moet uniek zijn; het is de onderste byte van elk CAN-adres |
| CAN Baud Rate | 500k | 500k | Ruim genoeg voor twee knopen op 50 Hz, robuust over lengte |
| CAN Status Message Mode | 1 – 5 | 1 – 5 | Levert eRPM, stroom, duty, temperaturen, tacho en `v_in` zonder pollen |
| CAN Status Rate | 50 Hz | 50 Hz | 20 ms per meting; snel genoeg voor stall- en runaway-detectie |
| Multiple VESCs Over CAN | uit | uit | Die functie spiegelt één gascommando naar alle VESC's — aan betekent: niet kunnen sturen |
| Timeout | 500 ms | 500 ms | Gratis deadman, zie hieronder |
| Timeout Brake Current | 0 A | 0 A | Uitrollen bij verlies van commando, niet remmen op een onbekende situatie |
| App to Use | UART / CAN | UART / CAN | Niet ADC — dat houdt AD2 vrij voor het temperatuursignaal |
| Speed PID min ERPM | 150 | 150 | Standaard staat dit veel hoger; met een hoge waarde regelt hij onder ~1,4 km/h niet |

**De timeout is de belangrijkste failsafe.** Stopt de Jetson met sturen — crash,
kernel panic, kabel eruit getrild — dan zetten beide VESC's zichzelf na 500 ms
uit. Dat werkt óók als deze software niet meer draait. Daarom zendt de
regellus in `app/services/vehicle_controller.py` onafgebroken op 50 Hz, ook als
er niets verandert.

### Waarom geen Arduino in het stuurpad

De verleiding is groot: er ligt er al een, en een MCP2515-module kost drie euro.
Toch niet doen, en de zwaarste reden is niet de latency maar de failsafe.

**Een tussenliggende Arduino maakt de VESC-timeout stuk.** Die timeout beschermt
tegen een dode Jetson doordat er dán geen frames meer komen. Zet je er een
Arduino tussen die het laatste commando blijft herhalen, dan blijven de frames
komen terwijl het brein al dood is — en rijdt de robot vrolijk door. Je kunt dat
repareren met een heartbeat-timeout in je eigen firmware, maar dan hangt je
belangrijkste beveiliging aan code die jij geschreven hebt in plaats van aan een
instelling in de controller. Dat is een ruil de verkeerde kant op.

Daar komt bij: **je ontsnapt niet aan de transceiver.** Of je nu een
MCP2515-module pakt of de CAN-controller die in de UNO R4 zelf zit (D4/D5, met
`CanExtendedId()` voor de 29-bits ID's die de VESC gebruikt) — er moet hoe dan
ook een transceiver tussen, en langs 48 V fasedraden bij voorkeur een
geïsoleerde. De Arduino vervangt dus niet het onderdeel dat je wilde vermijden;
hij komt er alleen vóór te staan.

En je raakt je gereedschap kwijt. Met socketcan debug je met `candump`,
`cangen` en python-can; met een brug debug je met `Serial.print` in firmware die
je zelf onderhoudt. Dat verschil voel je precies tijdens het in bedrijf stellen,
wanneer je het nodig hebt.

*Doorvoersnelheid is hier overigens niet het bezwaar:* op een UNO R4 is `Serial`
native USB CDC, dus die 500 frames per seconde passen er ruim door. Bij een
klassieke Arduino met MCP2515 op 115200 baud is dat wél het plafond, en dan komt
daar nog bij dat de MCP2515 maar twee ontvangstbuffers heeft.

**Waar de Arduino wél hoort:** de twee stuurstappenmotoren (daar zit hij al, en
step/dir-timing is precies microcontrollerwerk), en als inleeskanaal voor 5 V
dingen die de Jetson niet heeft — een RC-ontvanger voor handbediening,
bumperschakelaars, eindschakelaars. Die meldt hij via USB aan de Jetson.

**En niet als noodstop.** Die hoort een fysieke contactor in de acculeiding te
zijn met de knop in de spoelkring — geen microcontroller die zelf ook kan
vastlopen.

### De CAN-connector op de VESC

JST-GH, 4-polig. Tabel 2 van de VESC Classic 100V datasheet:

| Pin | Naam | Functie | Limiet |
|---|---|---|---|
| 1 | 5V | Power Out | 1 A |
| 2 | CANH | CAN | ±60 V |
| 3 | CANL | CAN | ±60 V |
| 4 | GND | Ground | 1 A |

> **Er zit één CAN-connector op een board.** Drie knopen op één bus (Jetson +
> twee VESC's) betekent dus een T-split of een klein verdeelprintje in de
> kabelboom — je kunt niet netjes doorlussen zoals bij boards met twee
> CAN-poorten.

> **Verbind pin 1 (5 V) niet tussen de twee VESC's door.** Dat is bij allebei
> een *uitgang*; twee voedingen tegen elkaar aan knopen levert een kringstroom
> op. Tussen de boards lopen alleen **CANH, CANL en GND**. Die 5 V is wél
> bruikbaar om de veldzijde van een geïsoleerde transceiver te voeden.

### De Jetson-kant: twee routes

De Jetson in deze machine is een **Orin Nano 16GB dev kit**.

**Route A — geïsoleerde USB-CAN-adapter (aanbevolen om mee te beginnen).**
Hij verschijnt als een gewone socketcan-interface en werkt met hetzelfde
`ip link`-commando als hieronder; je hoeft niets aan de device tree te doen.
**Op deze Orin Nano is dat `can1`**: `can0` is de eigen CAN-controller van de
Jetson (mttcan), en JetPack 6 heeft `gs_usb` niet standaard aan boord. De
driver wordt met DKMS gebouwd, zie
`setup/information/innomaker_usb2can_jetson_setup.json`.
Neem er een met echte galvanische isolatie: de bus loopt langs 48 V fasedraden,
en de datasheet waarschuwt zelf voor aardlussen bij USB-verbindingen. Let op het
verschil tussen twee soorten:

* **gs_usb / candleLight** (bijvoorbeeld een CANable of de InnoMaker): native
  socketcan, werkt met `can_interface: "socketcan"` en `can_channel: "can1"`
  uit de config.
* **slcan** (seriële CAN over een `/dev/ttyACM*`): daar hoort `slcand` bij, of
  je zet `can_interface` op `"slcan"` met het tty-pad als `can_channel`.

#### Welke adapter wel, en welke niet

Er zijn twee soorten die allebei "USB naar CAN" heten en niet hetzelfde zijn.

**Wel bruikbaar: een socketcan-adapter.** De productpagina noemt dan
*SocketCAN*, *gs_usb*, *candleLight* of een mainline Linux-driver (`peak_usb`).
Hij verschijnt als netwerkinterface `can0` en werkt met `ip link`, `candump` en
python-can zonder verdere software.

Een model dat aan alle eisen voldoet is de **InnoMaker USB2CAN-Module**: een
STM32F0 met gs_usb-firmware (dus `can0`, driverloos vanaf kernel 5.4) en een
**ISO1050** als transceiver — letterlijk de geïsoleerde transceiver die hierboven
wordt aanbevolen, met 1,5 kVDC/min isolatie. Hij heeft een **120 Ω terminator op
een jumper** aan boord, en zowel een D-SUB 9 als een schroefklem. Alternatieven
in dezelfde categorie: CANable 2.0 / CANable Pro (geïsoleerd) en PEAK PCAN-USB.

**Niet bruikbaar: een UART-CAN-brug met een CH340.** Dat zijn de goedkope
€15-modules die je bedient met een meegeleverd Windows-programma en AT-commando's
over een seriële poort. Ze verschijnen als `/dev/ttyUSB0`, nooit als `can0`. Je
kunt er geen willekeurige 29-bits extended ID's mee sturen zonder hun protocol
zelf na te bouwen, en het ontvangstverkeer hier — vijf statusframes per
controller op 50 Hz, dus circa 500 frames per seconde — loopt tegen de
bandbreedte van de seriële poort aan.

#### Wat die isolatie wel en niet doet

**Wel:** de CAN-kabel is geen massalus meer. Er loopt geen retourstroom door je
signaalmassa, en gaat er iets mis aan de 48 V-kant, dan plant die fout zich niet
voort naar de Jetson. Dat is de reden om hem te kopen. De ISO1050 heeft een
SiO₂-barrière (2,5 kVrms voor de DUB-uitvoering) en een transiëntimmuniteit van
50 kV/µs, dus de barrière zelf glitcht niet van een steile flank.

**Niet:** de buszijde van de adapter zelf beschermen. De CANH/CANL-pinnen van de
ISO1050 mogen **−27 V tot +40 V** zien; de CAN-pinnen van de VESC mogen ±60 V.
De adapter is daar dus de zwakkere van de twee. Schuurt er een fasedraad tegen
een CAN-draad, dan overleeft de VESC het mogelijk en de adapter niet.

**Ook niet:** overspanning wegvangen. Isolatie is geen TVS. Wil je dat er wel
bij, dan horen er TVS-diodes van CANH en CANL naar de busmassa en eventueel een
common-mode smoorspoel. Belangrijker en gratis: de CAN-bundel uit de buurt van
de fasedraden houden.

**En let op waar de echte spanningspieken in deze machine zitten:** niet op de
CAN-bus, maar op de DC-bus — teruglevering in een vol pak, en slepen met de
wielen aan de grond terwijl de hoofdschakelaar uit staat. Daar doet de isolatie
van je CAN-adapter niets tegen; dat is waar de taper op `v_in`, de precharge en
de sleepregels voor zijn. Zie *Remmen, hellingen en de accu*.

**In deze machine pakt dat gunstig uit.** De Jetson hangt aan een EGO-omvormer
(230 V AC) met zijn eigen netvoeding erachter, en de VESC's aan een 56 V
EGO-accu. Tussen die twee zitten dus al twee transformatoren: de massa's zijn
niet via de voeding verbonden. Zonder geïsoleerde adapter zou de CAN-massadraad
de *enige* verbinding tussen beide domeinen worden — een dunne signaaldraad als
massaverbinding tussen een zwevend 230 V-eiland en de accukring. Met de ISO1050
ertussen blijven ze gescheiden, en dat is hier dus geen halve maatregel maar
echte scheiding.

> Was de Jetson wél met een gewone, niet-geïsoleerde buck-converter uit hetzelfde
> pak gevoed, dan waren de massa's via de voeding alsnog verbonden en zat de winst
> alleen in het weghalen van de massalus.

**De test in één regel**, als je er al een hebt of twijfelt: steek hem in de
Jetson en kijk wat er verschijnt.

```bash
ip link | grep can        # can0 -> goed
ls /dev/ttyUSB* /dev/ttyACM*   # alleen dit -> seriële brug, niet bruikbaar
dmesg | tail -20          # welke driver hem heeft opgepakt
```

**Je hebt er één nodig, geen twee.** CAN is een bus: de adapter zet de Jetson
erop, en beide VESC's hangen aan diezelfde twee draden. Een tweede adapter zou
een tweede, losse bus maken — dat is precies de topologie die je met CAN wilde
vermijden. Zit de adapter aan een uiteinde van de bus, zet dan daar de ene
120 Ω terminator (veel adapters hebben er een aan boord of op een jumper) en de
andere bij de verste VESC.

**Route B — de CAN-controller van de Orin Nano zelf.** Die zit **niet op de
40-pins header**: op deze carrier zijn pin 29 en 31 gewoon GPIO01 en GPIO11, en
in de hele 40-pins tabel komt geen CAN voor. CAN staat op een **aparte header
J17**, 4-polig, 2,45 mm steek, waarvan de carrier-spec zegt dat het een
*footprint* is — kijk dus eerst of er op jouw bordje pinnen in zitten.

| J17 pin | Signaal | Richting |
|---|---|---|
| 1 | CAN_TX | uit, 3,3 V |
| 2 | CAN_RX | in, 3,3 V |
| 3 | GND | — |
| 4 | 3,3 V | voeding uit |

Dit is **logicaniveau, geen bus**: er hoort een transceiver tussen (ADM3053 of
ISO1050 met geïsoleerde DC-DC, geen kale SN65HVD230). Softwarematig heb je
pinmux- en device-tree-werk nodig voordat `can0` verschijnt; reken op een avond
uitzoekwerk. De winst is dat er geen USB-connector meer in het stuurpad zit.

### Bus fysiek

* **Twisted pair plus een aparte GND-referentiedraad.** Vertrouw niet op het chassis.
* **120 Ω alleen aan de twee fysieke uiteinden.** De datasheet noemt geen
  ingebouwde terminator, dus ga ervan uit dat je ze zelf plaatst. Meet met de
  accu los tussen CANH en CANL: je hoort **~60 Ω** te zien. 40 Ω betekent drie
  terminators, 120 Ω betekent er één.
* Houd de CAN-bundel weg bij de fasedraden; kruis ze haaks waar het niet anders kan.

Interface opbrengen op de Jetson:

```bash
sudo ip link set can0 up type can bitrate 500000 restart-ms 100
```

Zonder `restart-ms` blijft de interface dood na één bus-off. Gebruik
`setup/can0.service` om dit bij elke boot te doen. Controleren of er verkeer is:

```bash
candump can0
```

Je hoort dan van beide ID's statusframes op 50 Hz binnen te zien komen, ook
zonder dat de robotsoftware draait.

---

## Motor Settings (VESC Tool)

| Parameter | Waarde | Waar het vandaan komt |
|---|---|---|
| Motor Type | FOC | Sinusvormig, vol koppel vanaf stilstand, stil bij lage snelheid |
| Sensor Port Mode | Hall | Verplicht: bij 6 km/h zit je op ~3 900 ERPM, sensorloos is daar onbetrouwbaar |
| Motor Current Max | 15 A | 44% minder warmte dan 20 A (warmte schaalt met I²). Kost 25% piekkoppel |
| Motor Current Max Brake | −10 A | Conservatief; regen belast dezelfde wikkeling |
| Battery Current Max | 20 A | Motorspec: max output 20 A. De Quinder-controller limiteerde op 18 ±1 A |
| Battery Current Max Regen | 0 A | Voorlopig — tot je gemeten hebt wat de EGO-accu aanneemt |
| Absolute Maximum Current | 30 A | Vangnet ruim boven bedrijf, ruim onder wat 2,5 mm² aankan |
| Battery Voltage Cutoff Start | 42,0 V | Motorspec: undervoltage 41 ±1 V |
| Battery Voltage Cutoff End | 40,0 V | Volledig uit, onder de undervoltage-grens |
| Max ERPM | 3 900 | = 6 km/h. Absoluut plafond is 4 570 ERPM (7 km/h) — DaviLot: nooit sneller |
| Motor Temp Sensor | Disabled | De Quinder-sensor is geen NTC; zie *Temperatuursignaal* |

**Boost in plaats van een vaste 20 A.** Houd de limiet op 15 A en til hem
bewust naar 20 A als je uit een kuil vermogen nodig hebt, met een teller die hem
na maximaal 10 s terugzet. Piekkoppel als je erom vraagt, onder toezicht,
begrensd in tijd.

### Over het configbestand in deze map

`vesc_mcconf_openagbot_bruut_500_watt_hubmotor.xml` is het **oude profiel van een
ander board** en bevat motorparameters (R, L, flux linkage, halltabel) die niet
van deze Quinder-motor zijn. Schrijf dat bestand dus niet blind naar een VESC.

De werkwijze is andersom: sluit aan, doe **Read Motor Configuration**, voer de
limieten hierboven in, draai de **FOC-detectie**, en exporteer daarna het
resultaat naar deze map. Dat geëxporteerde bestand is het echte configbestand.
Een firmware-flash kan de configuratie resetten — controleer je limieten na
élke flash.

---

## Bedrading motor → VESC

Kabel: 3 × 2,5 mm² + 8 × 0,14 mm², 200 mm.

> **Blauw, groen en geel komen twee keer voor.** De fasedraden én de
> hall-signaaldraden zijn blauw, groen en geel. Onderscheid ze op dikte:
> **2,5 mm² is fase, 0,14 mm² is hall.** Verwissel je die, dan blaas je de
> hall-sensoren op.

| Draad | Ø mm² | Functie | Naar VESC |
|---|---|---|---|
| Blauw | 2,5 | Motorfase A | Fase-uitgang |
| Groen | 2,5 | Motorfase B | Fase-uitgang |
| Geel | 2,5 | Motorfase C | Fase-uitgang — draait hij verkeerd om, wissel er twee |
| Rood | 0,14 | Hall Sensor + | Sensorconnector · +5V |
| Zwart | 0,14 | Hall Sensor − | Sensorconnector · GND |
| Blauw | 0,14 | Hall signaal A | Sensorconnector · H1 |
| Groen | 0,14 | Hall signaal B | Sensorconnector · H2 |
| Geel | 0,14 | Hall signaal C | Sensorconnector · H3 |
| Wit | 0,14 | Toerentalpuls (6/omw) | Niet aansluiten — de VESC telt zelf via de halls, tienmaal fijner |
| Paars | 0,14 | Temperatuursignaal | Via deler → IO-connector · AD2 |

De hall-volgorde is niet kritisch bij het aansluiten: de FOC-detectie meet de
tabel zelf uit. Klopt de draairichting niet, wissel dan **twee fasedraden**,
niet de halls. De datasheet noemt 8 dunne draden en hierboven staan er 7 — kijk
wat de achtste is (reserve of afscherming) voordat je de boom afknipt. De
motorkabel is maar 200 mm; je hebt een verlengboom nodig.

### Temperatuursignaal op AD2

De motor heeft een temperatuuruitgang, maar het is **geen NTC**: hij geeft
actief spanning af. Daarom kan hij niet op de TEMP-pin van de sensorconnector
(10k pull-up naar 3,3 V, die zou tegen de sensoruitgang in vechten). Gebruik AD2
met een deler ÷2.

```
IO-CONNECTOR                        SENSORCONNECTOR
paars (temp) ──[10k]──┬── AD2       rood  (Hall +) ── +5V
                      │             zwart (Hall −) ── GND
                    [10k]           blauw (A) ─────── H1
                      │             groen (B) ─────── H2
                      ├──[100nF]    geel  (C) ─────── H3
                      │
                      └── GND
```

| Toestand | Aan de sensor | Na deler ÷2 | Actie |
|---|---|---|---|
| Normaal | 4,8 – 5,0 V | 2,4 – 2,5 V | Volle limiet |
| Waarschuwing · 105 °C | 1,09 V | 0,55 V | Terug naar 5 A, foutvlag |
| Afslag · 110 °C | 0,68 V | 0,34 V | Limiet naar 1 A |
| Draad los of gebroken | — | 0 V | Valt onder de afslagdrempel — faalt veilig |

Het Lisp-script hiervoor staat onderaan dit document.

---

## Wat de software doet

| Bestand | Rol |
|---|---|
| `app/hardware/vesc_can.py` | Protocol: frames bouwen en uitpakken, telemetrie per controller (STATUS 1–6, foutcode, herstart) |
| `app/hardware/motor_logic.py` | De twee achterwielen als geheel: m/s ↔ eRPM, min/max eRPM, verbindingsbewaking, beveiligingslagen 2 en 3 |
| `app/services/vehicle_controller.py` | Regellus op 50 Hz: Ackermann, elektronisch differentieel, acceleratiebegrenzing |
| `app/hardware/stepper_logic.py` | De twee voorwielen (stappenmotoren via Arduino) — ongewijzigd |
| `data/config.example.json` → `vesc`, `vehicle` | Alle waarden hierboven die de software nodig heeft |

### Rijgedrag

* **Onder 900 eRPM draait een wiel niet.** Dat is `Speed PID min ERPM`
  (`s_pid_min_erpm`) in de VESC: daaronder regelt hij niet meer en remt hij af.
  In `config.json` staat daarom `vesc.min_erpm` 900. Een wiel staat stil of
  draait minstens 1,38 km/h. Wegrijden gaat in één stap naar die 900 eRPM;
  verlaag je de VESC-instelling, dan kan `min_erpm` mee omlaag en trekt hij
  zachter op.
* **Maximaal `vesc.max_erpm`** (nu 3 000 = 4,6 km/h). Hoger kan, maar niet
  boven Max ERPM in de VESC zelf.
* **Elektronisch differentieel, exact uit de stuurgeometrie.** Een VESC houdt
  zijn toerental vast. Krijgen beide achterwielen in een bocht hetzelfde
  toerental, dan vechten ze via de grond tegen elkaar. Bij volle uitslag draait
  het binnenwiel ~19 % langzamer en het buitenwiel ~19 % sneller dan het midden.
  `vehicle.differential_gain` = 0 koppelt ze alsnog.
* **Wat niet kan, wordt opgelost met één factor voor beide wielen.** Zakt het
  binnenwiel onder 900 of komt het buitenwiel boven `max_erpm`, dan schalen
  beide wielen samen mee: de bocht blijft, de snelheid past zich aan. Dezelfde
  gedeelde factor zit in de ramp (`accel_mps2`, `decel_mps2`), zodat de bocht
  ook tijdens het optrekken klopt.
* **Navigatie rijdt alleen vooruit**, handmatig rijden mag achteruit tot
  `vesc.max_erpm_reverse`.
* **Geen één-wiel-rijden.** Geeft een VESC langer dan 0,5 s geen data, meldt
  hij een foutcode, loopt een wiel vast of wordt het model te heet, dan krijgen
  beide wielen 0 en stopt een lopende missie. Een vastgelopen wiel of een te
  hete motor blijft staan tot `POST /api/motors/reset`. Daarna rijdt hij pas
  weer op een nieuw commando.

Alle telemetrie staat op `GET /api/motors`. Een kort overzicht (`drive_fault`,
`accu_v`) zit in `GET /api/status`.

### Frames

Extended frame, 29-bits ID = `(commando << 8) | vesc_id`, payload big-endian.

| Cmd | Betekenis | Payload | Schaal |
|---|---|---|---|
| 1 | SET_CURRENT | i32 | × 1000 (mA) |
| 2 | SET_CURRENT_BRAKE | i32 | × 1000 |
| 3 | SET_RPM | i32 | eRPM, geen schaal — begrensd op `vesc.max_erpm` |
| 12 | SET_CURRENT_HANDBRAKE | i32 | × 1000 |
| 8 | PROCESS_SHORT_BUFFER | `COMM_GET_VALUES_SELECTIVE` met masker bit 15 | vraagt de foutcode op; antwoord komt in één frame terug |
| 9 | STATUS ↓ | i32 eRPM, i16 stroom, i16 duty | ÷ 10 · ÷ 1000 |
| 14 | STATUS_2 ↓ | i32 Ah verbruikt, i32 Ah teruggeleverd | ÷ 10 000 |
| 15 | STATUS_3 ↓ | i32 Wh verbruikt, i32 Wh teruggeleverd | ÷ 10 000 |
| 16 | STATUS_4 ↓ | temp FET, temp motor, stroom in, pid pos | ÷ 10 · ÷ 10 · ÷ 10 · ÷ 50 |
| 27 | STATUS_5 ↓ | i32 tacho, i16 `v_in` | tacho: 300 = één wielomwenteling · ÷ 10 |
| 57 | NOTIFY_BOOT ↓ | hardwarenaam in ASCII | eenmalig na elke (her)start |
| 58 | STATUS_6 ↓ | ADC1, ADC2, ADC3, PPM | ÷ 1000; alleen als hij in de VESC aan staat |

### Twee stromen, twee betekenissen

De telemetrie geeft per wiel **motorstroom** (STATUS) én **accustroom**
(STATUS_4). Dat zijn niet twee namen voor hetzelfde getal: de VESC is een
omvormer, geen weerstand. Bij lage duty ligt de motorstroom fors hoger dan wat
er uit de accu komt — bij een vastgelopen wiel op 20 A motorstroom ziet een
accuzijdige zekering maar ~1,7 A, en die merkt er dus niets van.

* **Motorstroom** bepaalt de warmte in de wikkeling. Hierop draaien de
  stall-detectie en het thermisch model, en hierop staat Motor Current Max.
* **Accustroom** bepaalt wat er door de zekering en de accukabel loopt, en is
  negatief tijdens teruglevering. Beide opgeteld is wat het pak levert — precies
  het getal dat de vraag "hoeveel regenstroom neemt de accu aan?" beantwoordt.

Je ziet ze naast elkaar in het aandrijfpaneel van de webinterface, op
`/api/motors` (`motor_current_a` en `input_current_a` per wiel, plus `accu_a` en
`accu_w` totaal) en in elke ritlog in `data/logs/`.

> **Handbrake is een greep, geen parkeerrem.** Bij nul toeren gaat alle
> handbrake-stroom als warmte de wikkeling in — precies het stall-scenario. De
> software gebruikt hem daarom niet: bij stilstand stuurt hij SET_RPM 0, net als
> het testscript, en onder Speed PID min ERPM remt de VESC het wiel dan af in
> plaats van het vast te houden.

### Beveiligingslagen, op volgorde van waarde per uur werk

| # | Laag | Waar | Reactietijd |
|---|---|---|---|
| 1 | Motor Current Max op 15 A | VESC-config | µs |
| 2 | Stall-detectie | `motor_logic.py` | 3 s |
| 3 | Thermisch model op de motorstroom | `motor_logic.py` | continu |
| 4 | VESC Timeout op 500 ms | VESC-config | 0,5 s |
| 5 | Zekering 30 A, ≥58 V DC | hardware | seconden |
| 6 | Temperatuursensor op AD2 + Lisp | op de controller zelf | 105 °C |

Laag 1 en 2 doen samen bijna al het werk. Laag 3 en 6 zijn elkaars aanvulling:
het model draait op de Jetson en is dood zodra die dood is; het Lisp-script
draait op de controller en blijft werken als de CAN-kabel eruit trilt.

**Een stroomlimiet is geen garantie.** Er bestaat geen stroomwaarde waarbij een
vastgelopen wiel veilig is. De motor is 9 A rated loading, en die 9 A geldt voor
een *draaiend* wiel met luchtstroming. 15 A is nog altijd ~1,7× overbelasting —
een pieklimiet, geen vrijbrief.

### Het thermisch model ijken

`motor_logic.py` schat de wikkelingtemperatuur uit de motorstroom die toch al op
50 Hz binnenkomt:

```
T += (i_motor**2 * thermal_k - T / thermal_tau_s) * dt
```

De startwaarden in `config.example.json` (`vesc.safety.thermal_k` 0,00123 en
`thermal_tau_s` 600) zijn
berekend, niet gemeten: ze komen uit op ~60 °C boven omgeving bij 9 A continu.
Boven `motor_warn_c` (90 °C) komt er een waarschuwing, boven `motor_trip_c`
(105 °C) stopt de aandrijving tot een reset. De schatting staat per wiel als
`motor_temp_model_c` in `/api/motors` en als `Motortemp_model_L_C` / `_R_C` in
de ritlog.
IJk ze één keer tegen de drietrapssensor: draai op een bekende stroom tot de
sensor bij 105 °C omslaat en noteer hoe lang dat duurde. Reken conservatief bij
stilstand — zonder luchtstroom is `tau` langer. Log `T` mee in het veld; daarmee
kies je uiteindelijk je definitieve 15 A op meetwaarden in plaats van op een
vuistregel.

---

## Remmen, hellingen en de accu

**Er zit nergens een mechanische rem.** Het wiel draait met de hand vrij naar
beide kanten; de 5 : 1 kast blokkeert niet tegendraads. Wat de robot tegenhoudt
is uitsluitend wat de VESC elektrisch doet — en dat werkt alleen als de accu de
energie aanneemt. Staat alles uit, dan rolt hij.

Dit is geen instelling die je goed of fout kunt zetten; het is een
vermogensbalans. Zwaartekracht levert een vermogen dat lineair met je snelheid
meegroeit, je rem kan een vast maximum wegzetten. Zodra de helling er net
overheen gaat is er géén snelheid meer waarbij het in evenwicht komt: je
versnelt, de zwaartekracht levert méér, je versnelt harder.

| Regen per VESC | Totaal | Houdt bij 6 km/h | Houdt bij 3 km/h |
|---|---|---|---|
| −3 A | 6 A · 312 W | ~4 % | ~8 % |
| −5 A | 10 A · 520 W | ~6 % | ~13 % |
| −10 A | 20 A · 1 040 W | ~13 % | ~25 %* |

Vuistregel bij 6 km/h: elke ampère teruglevering koopt ~0,6 % helling. Afgeleid
uit `m·g·sin(θ)·v` bij 500 kg en 52 V. \* De lage-snelheidskolom loopt eerder
tegen de 15 A motorlimiet aan dan tegen het vermogen — bovengrens, geen belofte.

### Voeding van deze machine

| Verbruiker | Bron |
|---|---|
| Twee VESC's | 56 V EGO-accu (14S, vol 58,8 V) |
| Jetson | EGO-omvormer 230 V AC, met de eigen netvoeding van de dev kit |

Twee dingen volgen daaruit.

**De regen-cutoff in de VESC is op dit pak gesneden.** Battery Voltage Regen
Cutoff 56,0 V als begin en 57,5 V als eind horen bij een 14S EGO; wissel je van
accutype, dan moeten die twee mee.

**Hangt de omvormer aan hetzelfde pak als de VESC's?** Zo ja, dan zakt je
Jetson-voeding mee op het moment dat de aandrijving het hardst trekt — een
20 A-piek uit een kuil is precies wanneer je hem niet wilt verliezen — en valt
alles tegelijk uit als de BMS afschakelt. Een eigen accu voor de omvormer haalt
dat koppel uit elkaar: de aandrijving mag dan leegraken zonder je brein mee te
nemen. Reken bij één gedeeld pak in elk geval na of de omvormer zijn eigen
laagspanningsgrens niet eerder haalt dan de 42 V waarop de VESC's terugregelen.

De EGO-accu néémt regen aan, maar **bij een vol pak valt de rem weg**. Dat is
bekend EGO-gedrag en geldt voor élke volle accu. De overspanningsbeveiliging van
de VESC helpt niet: dit is een 100 V board en je pack gaat tot 58,8 V. Wat de
VESC wél doet is de teruglevering afbouwen via Battery Voltage Regen Cutoff.
Het bijpassende **snelheidsplafond zit nog niet in de software**:

| Gemeten `v_in` | Regen (VESC) | Snelheidsplafond (nog te bouwen) |
|---|---|---|
| < 56,0 V | vol | Normaal |
| 56,0 – 57,5 V | lineair naar nul | Evenredig terug |
| > 57,5 V | geen | Stapvoets |

Let bij het bouwen op dat `v_in` onder belasting inzakt en bij remmen oploopt:
een plafond rechtstreeks op de gemeten spanning gaat pompen. Gebruik de
rustspanning, of compenseer met stroom × pakweerstand, en filter traag. Tot dat
plafond er is, geldt de bedrijfsregel hieronder. De accuspanning staat al als
`accu_v` in `/api/motors` en als `Accu_V` in de ritlog. Omdat `P = F · v` houdt dezelfde rem bij de halve
snelheid de dubbele helling: **volle accu betekent weinig ruimte betekent
langzaam naar beneden.** Dat is de enige mitigatie die de natuurkunde aan jouw
kant zet.

Wat het werkelijk oplost: een **remweerstand op de bus** (MOSFET met
vermogensweerstand boven ~57 V, ~4 Ω ≈ 850 W ongeacht laadtoestand), of een
**veerbelaste elektromagnetische rem op de as** — het enige dat ook werkt als de
VESC uit staat. Tot die er zijn geldt de bedrijfsregel: geen hellingen op die je
niet uitrollend kunt verlaten, en nooit vol beginnen aan een perceel met helling.

---

## Lisp-script voor de temperatuurbeveiliging

VESC Tool → Scripting. Draait op de controller zelf en blijft dus werken als de
Jetson vastloopt.

```lisp
(def i-max (conf-get 'l-current-max))   ; bewaar de geconfigureerde 15 A
(def v-warn 1.50)   ; boven deze waarde: normaal
(def v-trip 0.45)   ; onder deze waarde: afslag (of draad los)

(loopwhile t
  (progn
    (def v (get-adc 1))                 ; kanaal 1 = AD2
    (if (< v v-trip)
        (conf-set 'l-current-max 1.0)
        (if (< v v-warn)
            (conf-set 'l-current-max 5.0)
            (conf-set 'l-current-max i-max)))
    (sleep 0.2)))
```

`conf-set` schrijft niet naar flash: na een reboot sta je automatisch weer op je
veilige 15 A. Kalibreer `v-warn` en `v-trip` op wat je werkelijk terugleest, en
controleer de syntax tegen jouw firmwareversie — LispBM is nog in beweging.

---

## Bankprocedure

In deze volgorde, vóór het eerste veldgebruik:

1. **Precharge eerst.** XT90-S of een voorlaadweerstand; dit board heeft flinke
   condensatoren.
2. **Wiel vrij van de grond.** Bok of klem, vóórdat er spanning op staat.
3. **Limieten invoeren en opslaan** vóór je de motor aankoppelt. Doe eerst
   *Read Motor Configuration* — wat VESC Tool offline toont zijn defaults van
   een ander hardwareprofiel.
4. **Stock-controller volledig van de fasedraden af.** Blijft hij eraan hangen,
   dan laadt de VESC via zijn body-diodes diens buscondensatoren op.
5. **FOC-detectie draaien** met de halls aangesloten. Noteer de gemeten R en L.
6. **Draairichting controleren.** Verkeerd om? Twee fasedraden wisselen.
7. **ERPM-limiet verifiëren:** vol commando moet uitkomen op 3 900 ERPM.
8. **Odometrie controleren:** één wielomwenteling met de hand = 300 tellen.
9. **CAN-bus opbouwen:** unieke ID per board, 500 kbit/s, statusframes 1–5 op
   50 Hz. Meet ~60 Ω tussen CANH en CANL met de accu los.
10. **Timeout aantoonbaar maken:** laat een wiel draaien en trek de CAN-kabel
    eruit. Hij hoort binnen een halve seconde uit te vallen. Test dit één keer
    bewust — het is je belangrijkste failsafe.
11. **Meetronde in het veld** met telemetrie aan (`/api/motors` of de CSV-logs
    in `data/logs/`). Dáárop kies je je definitieve 15 A en ijk je het model.
12. **Configbestand exporteren en in deze map zetten.**

### Onthouden

* **Houd de Quinder-controller heel.** Niet de kabelboom doorknippen: hij is je
  terugvaloptie én je meetreferentie. Wel volledig loskoppelen van de fasedraden.
* **Zekering: 30 A, niet 25 A**, en controleer de **DC**-spanningswaarde —
  auto-steekzekeringen zijn vaak op 32 V DC gespecificeerd, jij zit tot ~58 V.
* **Nooit sneller dan 7 km/h.** Bij slepen met de wielen aan de grond: 5 km/h.
* **Sleep nooit met de hoofdschakelaar uit.** Rollende wielen maken de motor tot
  generator, en die spanning komt via de body-diodes altijd op de bus. Met de
  accu erop wordt hij geklemd; zonder accu laadt hij de buscondensatoren op tot
  niets hem meer tegenhoudt. De accu is hier de bescherming, niet het slachtoffer.
* **Precharge ook na een sleepbeurt** met de schakelaar uit.
* **Verwissel nooit + en −.** Dat sloopt de hall-sensoren, en die zitten in een
  IP66-behuizing.

---

## Rekenwaarden

Herbereken deze als je van band, tandwielkast, massa of accuspanning wisselt.

| Grootheid | Waarde | Afleiding |
|---|---|---|
| Bandomtrek | 1,277 m | Buitenmaat 16" = 406,4 mm × π |
| Poolparen | 10 | 2P = 20 polen |
| Overbrenging | 5 : 1 | Zelfsmerende binnentandwielkast |
| ERPM per wiel-RPM | × 50 | 5 (kast) × 10 (poolparen) |
| 6 km/h | 3 917 ERPM | 78,3 wiel-RPM × 50 |
| 7 km/h — nooit hoger | 4 569 ERPM | 91,4 wiel-RPM × 50 |
| Tellen per wielomwenteling | 300 | 6 stappen/elek.omw × 10 poolparen × 5 |
| Odometrieresolutie | 4,26 mm | 1 277 mm ÷ 300 |
| Continu belastbaar | 9,0 A · 75 RPM | Rated loading ≈ 5,7 km/h |
| Maximaal | 20 A · 55 RPM | Max output ≈ 4,2 km/h, ≈ 1 kW ingangsvermogen |
| Massa (aslast) | 500 kg | Motorspec max axle load |
| Hellingvermogen bij 6 km/h | 8,2 kW per eenheid sin θ | 500 × 9,81 × 1,667 |
| Helling per ampère regen | ~0,6 % | 52 V ÷ 8 177 W, bij 6 km/h |
| Accu vol | 58,8 V | EGO 14S × 4,2 V — hier is de regenruimte nul |
| Overspanningsgrens board | 100 V | Tientallen volts boven de accu |

---

## Openstaande vragen

Af te vinken op de werkbank; de software draait ondertussen op veilige
startwaarden.

* Wie voedt de temperatuursensor? Sluit alleen +5 V en GND van de VESC aan en
  meet de paarse draad koud. ~4,8 V = klaar. 0 V = de voeding zat in de
  Quinder-controller.
* Werkt `get-adc` met App op UART/CAN, en geeft hij pinspanning of de gedeelde
  waarde? Eén meting met een multimeter ernaast beantwoordt beide.
* Is het temperatuursignaal drietraps of proportioneel? Meet tijdens een zware klim.
* Hoeveel regenstroom gebruikt de stock-controller? Stroomtang om de plusdraad
  tijdens remmen op een helling die hij nog wél houdt.
* Wat doet de firmware bij hoge busspanning tijdens regen — taperen of een
  `OVER_VOLTAGE`-fout? Een fout betekent dat de motor er in één klap uit gaat.
* Koppelt de BMS af bij een vol pak, of trekt de controller zich terug?

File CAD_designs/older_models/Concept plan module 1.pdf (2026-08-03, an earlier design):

# SNIJ- & KANTOPDRACHT WIELMODULES

4.0 mm Staal / IJzer | Geen lassen vereist

## 1. COMPLETE MODULE OVERZICHT

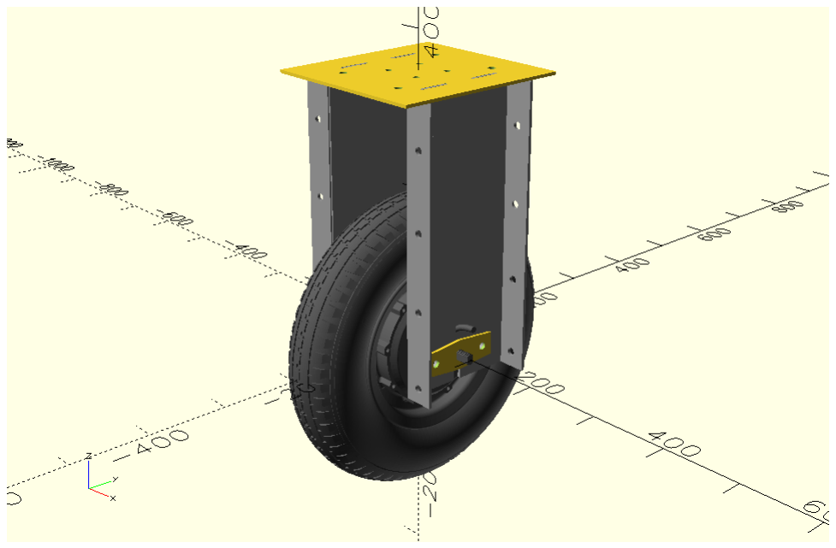
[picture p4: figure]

## 2. TOTAALOVERZICHT AANTALLEN

Project: Modulair Chassis Wielunits (4 complete sets)

Materiaal: Staal / IJzer (Dikte: 4.0 mm)

Bewerkingen: Lasersnijden + Kanten (Lassen is NIET nodig)

Max. Afmetingen Module:
228 mm (B) x 240 mm (L) x 380 mm (H)
Onderdeel | DXF Bestand | Afmeting
| | Uitslag (B x H) | Aantal /
| | | Module | Totaal
| | | | Aantal | Bewerking

Side Plate
(Zijplaat) | bracket_side_plate.dxf | 240 x 380 mm | 2 stuks | 8 stuks | Lasersnijden + 2x 90°
| | | | | Kanten (16 zettingen)

Axle Bracket
(Asplaatje) | axle_bracket.dxf | 110 x 40 mm | 2 stuks | 8 stuks | Lasersnijden (Plat)

Top Plate
(Bovenplaat) | bracket_top_plate.dxf | 228 x 240 mm | 1 stuk | 4 stuks | Lasersnijden (Plat)
TOTAAL | - | - | 5 stuks | 20 stuks | 16 Zettingen totaal

## 3. INSTRUCTIES SIDE PLATE (ZIJPLAAT)

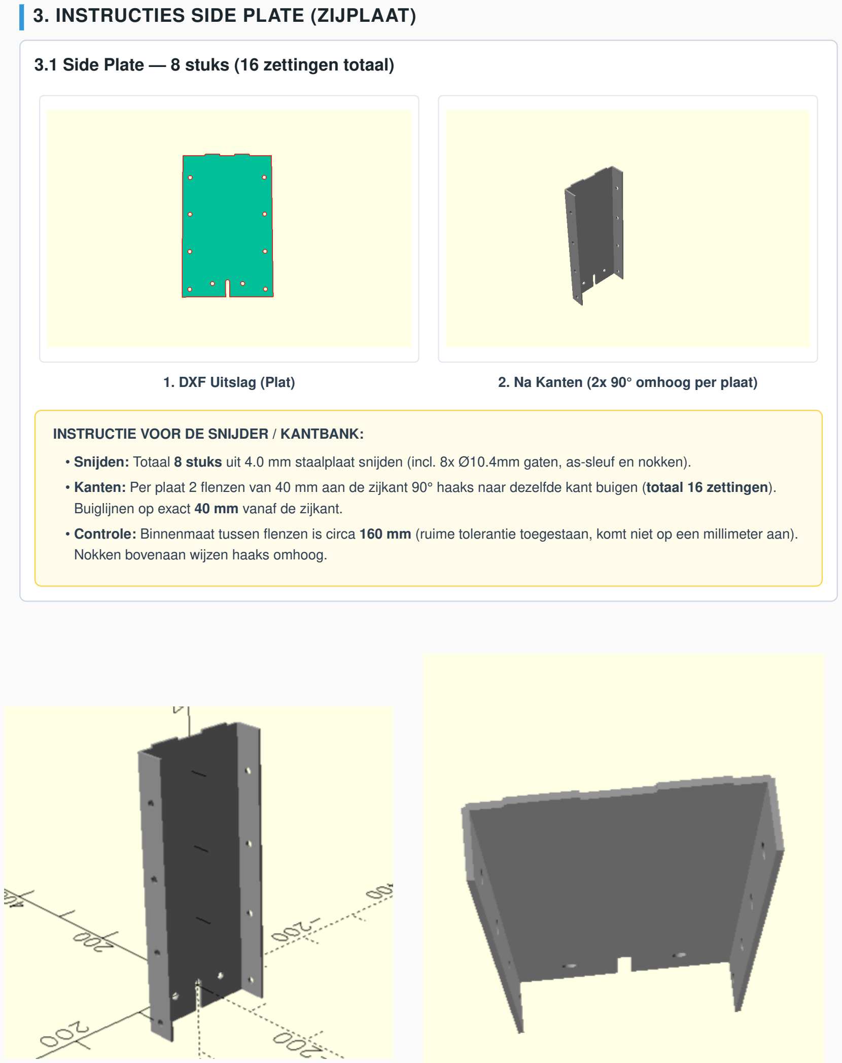
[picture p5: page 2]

### 3.1 Side Plate — 8 stuks (16 zettingen totaal)

INSTRUCTIE VOOR DE SNIJDER / KANTBANK:

Snijden: Totaal 8 stuks uit 4.0 mm staalplaat snijden (incl. 8x Ø10.4mm gaten, as-sleuf en nokken).

Kanten: Per plaat 2 flenzen van 40 mm aan de zijkant 90° haaks naar dezelfde kant buigen (totaal 16 zettingen). Buiglijnen op exact 40 mm vanaf de zijkant.

Controle: Binnenmaat tussen flenzen is circa 160 mm (ruime tolerantie toegestaan, komt niet op een millimeter aan). Nokken bovenaan wijzen haaks omhoog.

1. DXF Uitslag (Plat) | 2. Na Kanten (2x 90° omhoog per plaat)

•

•

•

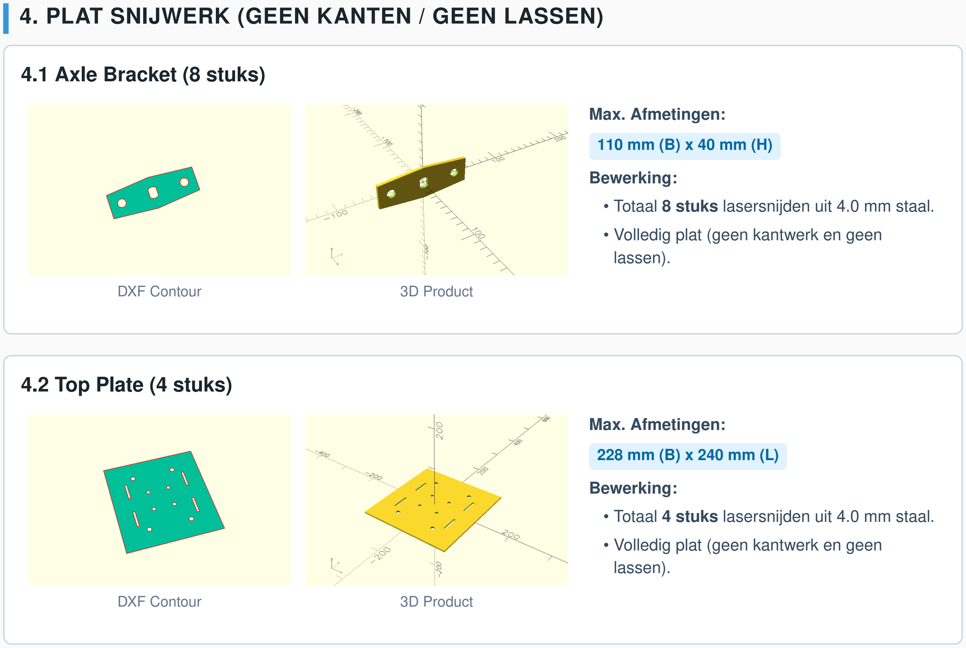
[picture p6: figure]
4.1 Axle Bracket (8 stuks); 4.2 Top Plate (4 stuks); DXF Contour; 3D Product; Max. Afmetingen:; Bewerking:; Volledig plat (geen kantwerk en geen lassen).

## 4. PLAT SNIJWERK (GEEN KANTEN / GEEN LASSEN)

Totaal 8 stuks lasersnijden uit 4.0 mm staal.

Totaal 4 stuks lasersnijden uit 4.0 mm staal.

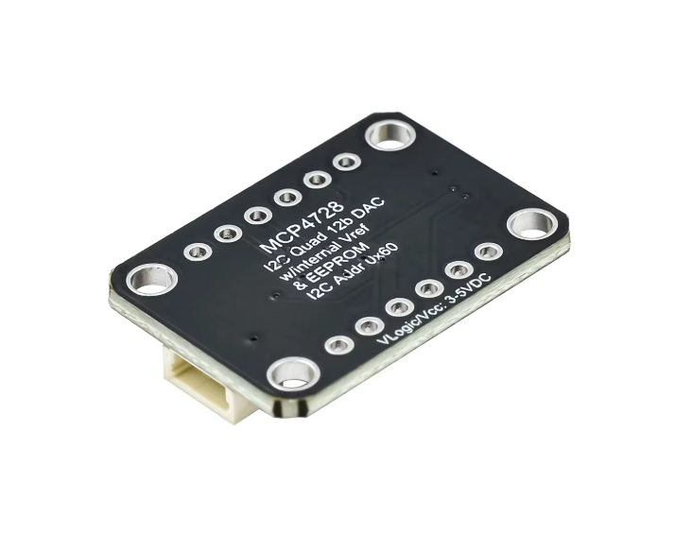
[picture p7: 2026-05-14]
setup/information/Specs hardware/images MCP4728 board/Schermafbeelding 2026-04-17 140433.png

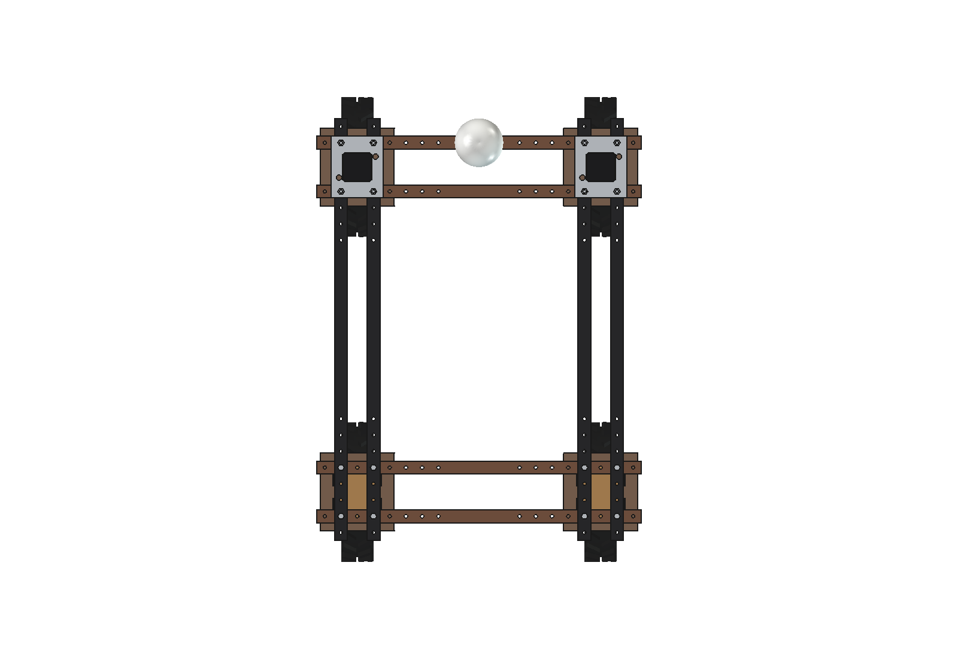
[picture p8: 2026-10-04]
CAD_designs/freecad/previews/4_top.png

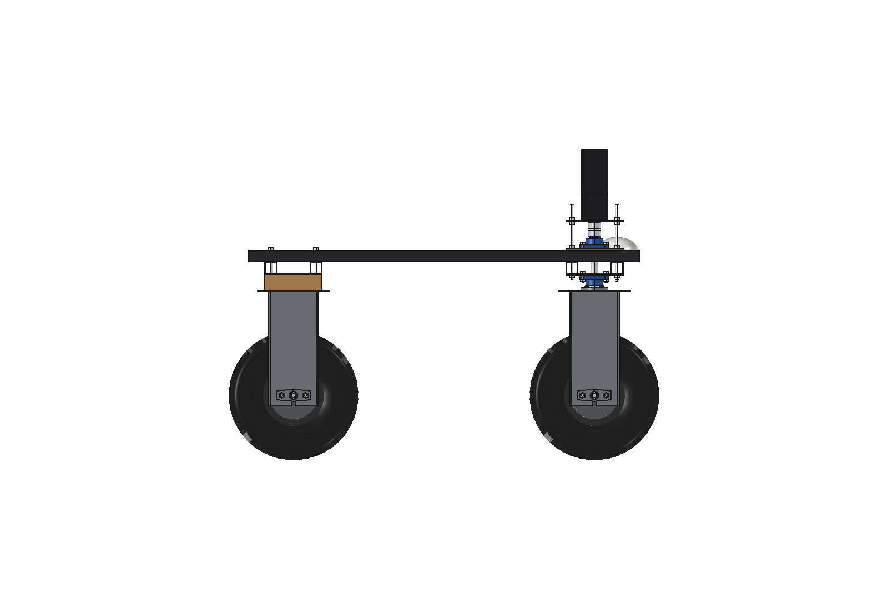
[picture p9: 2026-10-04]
CAD_designs/freecad/previews/5_side_right.png

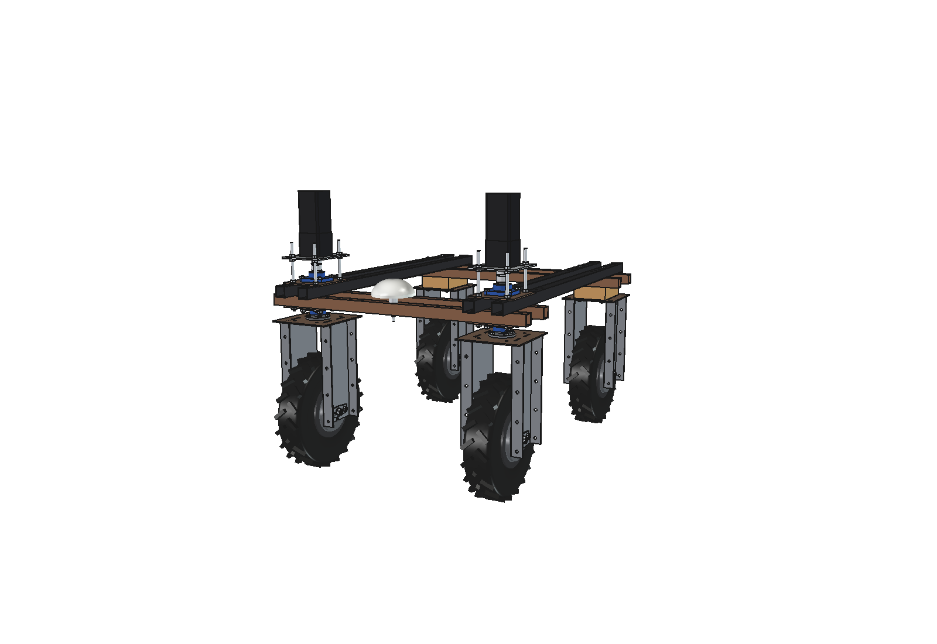
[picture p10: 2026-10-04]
CAD_designs/freecad/previews/2_robot_front_left.png

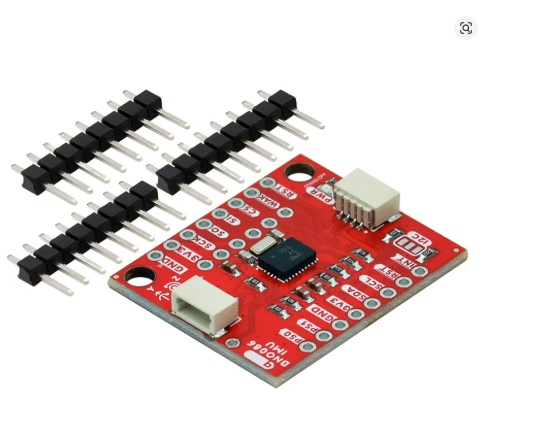
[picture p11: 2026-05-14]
setup/information/Specs hardware/images IMU/Schermafbeelding 2026-04-19 165255sfas.png

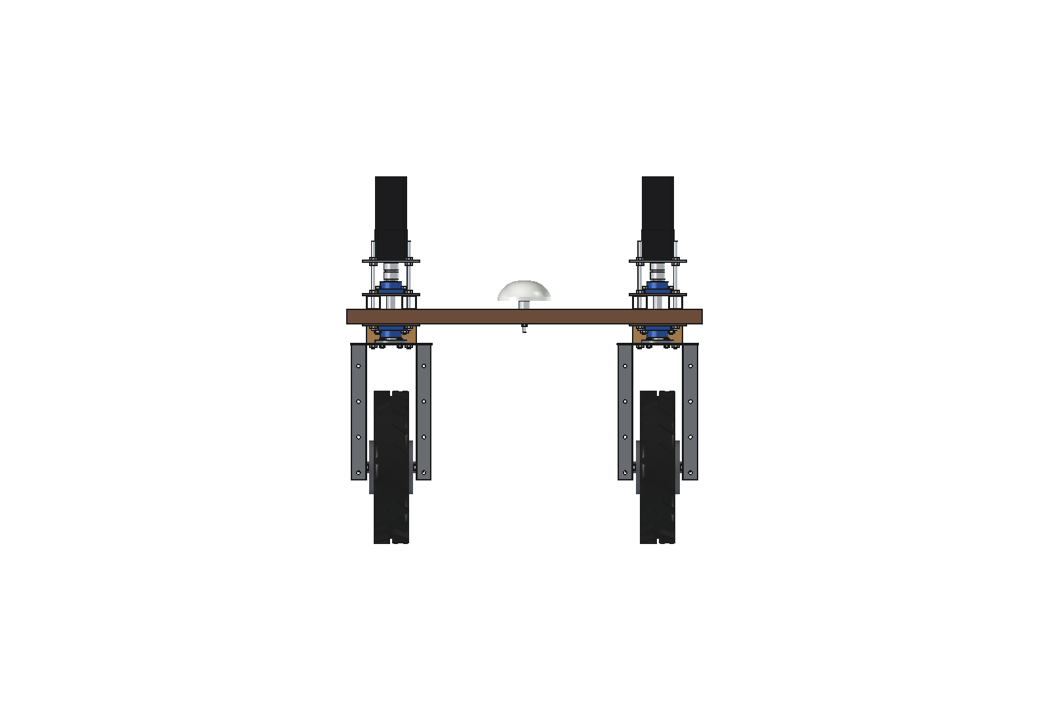
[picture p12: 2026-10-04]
CAD_designs/freecad/previews/6_rear.png

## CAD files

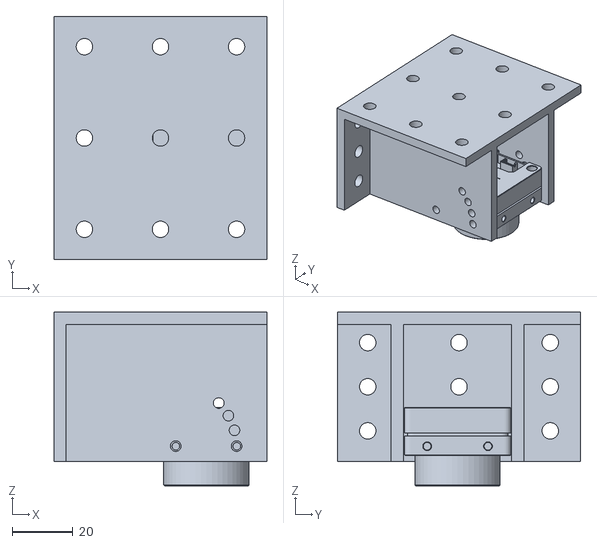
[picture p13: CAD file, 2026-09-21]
CAD_designs/accesories/Daheng_camera/va_imaging_camera_mount.stl
70.0 x 80.0 x 57.1

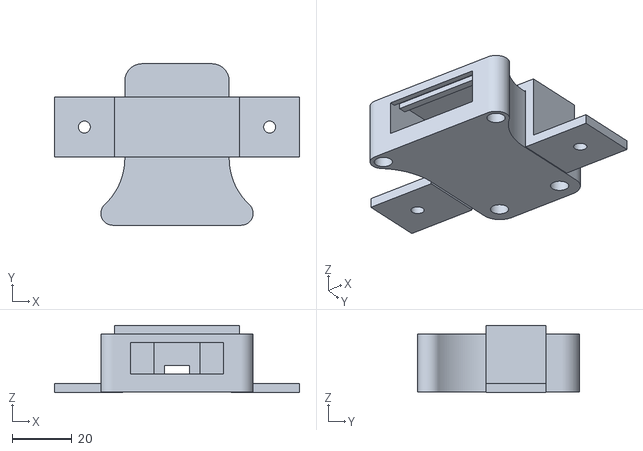
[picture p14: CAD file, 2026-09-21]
CAD_designs/accesories/USB2CAN innomaker/USB2CAN converter Innomaker clamp.stl
82.0 x 54.1 x 22.5

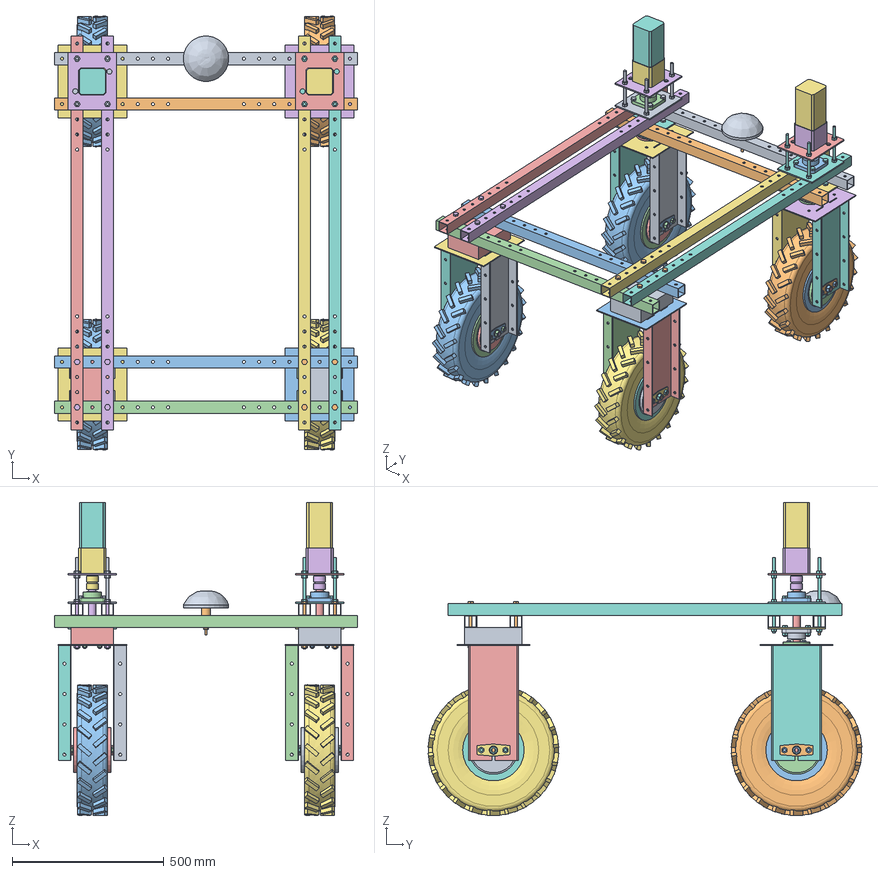
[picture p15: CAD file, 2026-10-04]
CAD_designs/freecad/Bruut_OpenAgbot.FCStd
1000.0 x 1431.7 x 1032.9 mm
chassis_beam_1_front_outer
chassis_beam_1_front_inner
chassis_beam_1_rear_inner
chassis_beam_1_rear_outer
chassis_beam_2_left_outer
chassis_beam_2_left_inner
chassis_beam_2_right_inner
chassis_beam_2_right_outer
gnss_antenna_dome
gnss_antenna_mount
tire_RL
rim_RL
hub_motor_RL
axle_RL
bracket_top_plate_RL
bracket_side_plate_left_RL
bracket_side_plate_right_RL
axle_bracket_left_RL
axle_bracket_right_RL
wheel_hardware_RL
wooden_spacer_block_RL
frame_bolts_RL
tire_RR
rim_RR
hub_motor_RR
axle_RR
bracket_top_plate_RR
bracket_side_plate_left_RR
bracket_side_plate_right_RR
axle_bracket_left_RR
axle_bracket_right_RR
wheel_hardware_RR
wooden_spacer_block_RR
frame_bolts_RR
tire_FL
rim_FL
hub_motor_FL
axle_FL
bracket_top_plate_FL
bracket_side_plate_left_FL
bracket_side_plate_right_FL
axle_bracket_left_FL
axle_bracket_right_FL
wheel_hardware_FL
steering_hub_flange_FL
steering_shaft_FL
shaft_coupling_FL
bearing_plate_lower_FL
bearing_plate_upper_FL
flange_bearing_lower_FL
flange_bearing_lower_ring_FL
flange_bearing_upper_FL
flange_bearing_upper_ring_FL
stepper_plate_FL
stepper_gearbox_5to1_FL
stepper_motor_nema34_FL
steering_hardware_FL
tire_FR
rim_FR
hub_motor_FR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

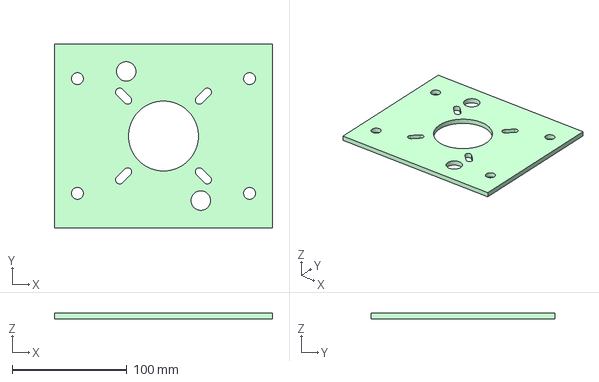
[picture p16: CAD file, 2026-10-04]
CAD_designs/parts/PLOATIE 2.STP
190.0 x 160.0 x 5.00 mm

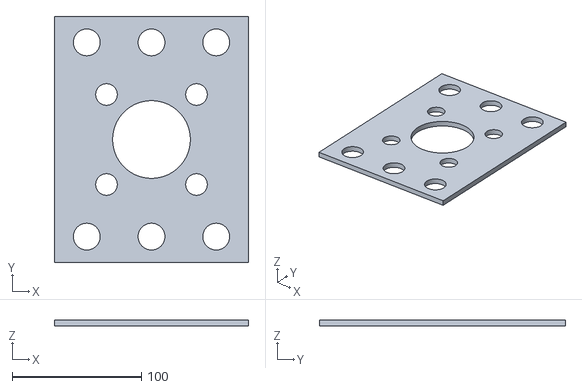
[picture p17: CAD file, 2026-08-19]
CAD_designs/templates/stl's/reducer_holes_template.stl
150.0 x 190.0 x 5.00

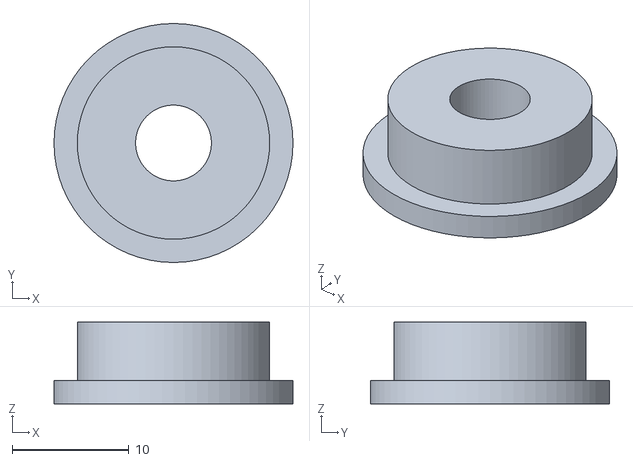
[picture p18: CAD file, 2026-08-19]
CAD_designs/templates/stl's/drill_bushing_m6.stl
20.5 x 20.5 x 7.00

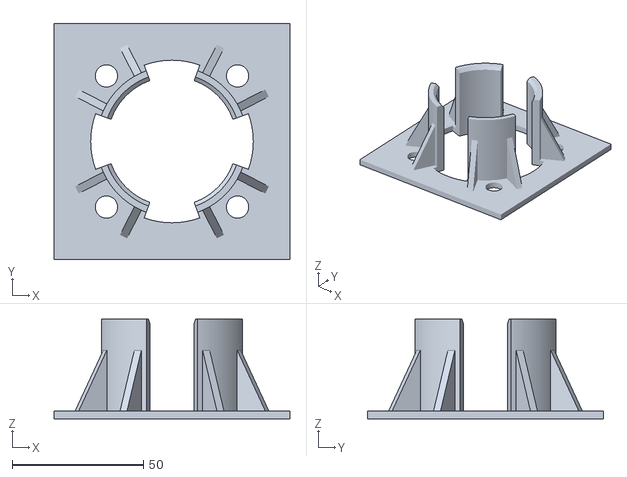
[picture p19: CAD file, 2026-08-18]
CAD_designs/templates/stl's/bracket_top_plate_pipe_center_template.stl
90.0 x 90.0 x 38.0

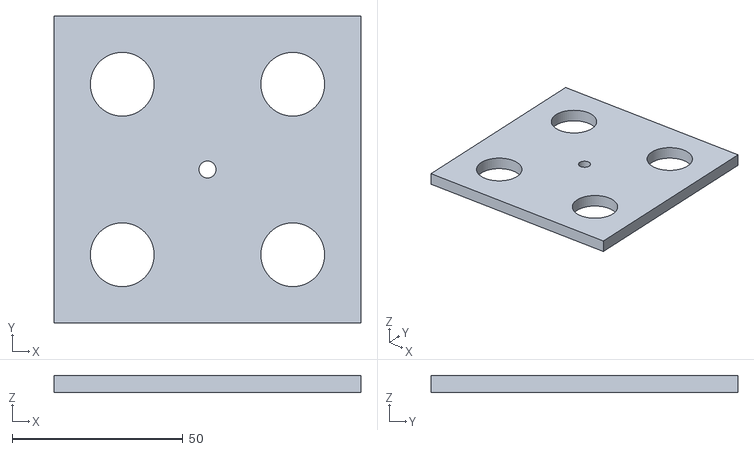
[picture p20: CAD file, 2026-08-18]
CAD_designs/templates/stl's/bracket_top_plate_holes_template_centrum.stl
90.0 x 90.0 x 5.00

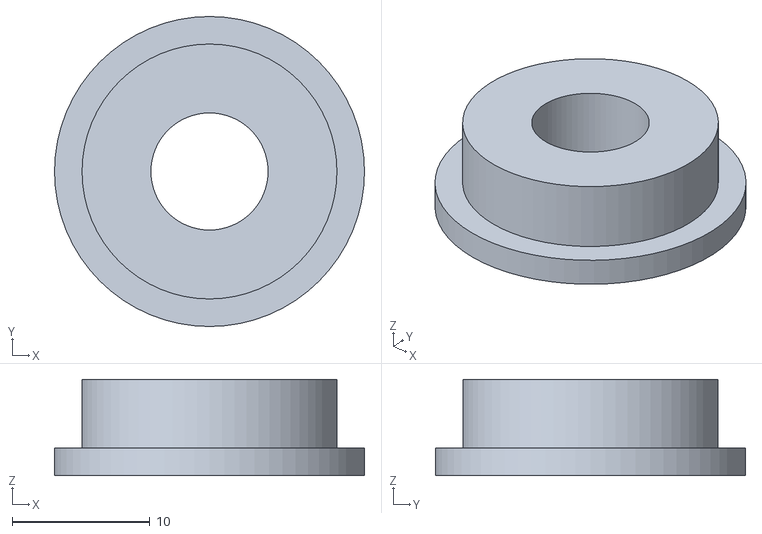
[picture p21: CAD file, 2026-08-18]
CAD_designs/templates/stl's/drill_bushing_m8.stl
22.5 x 22.5 x 7.00

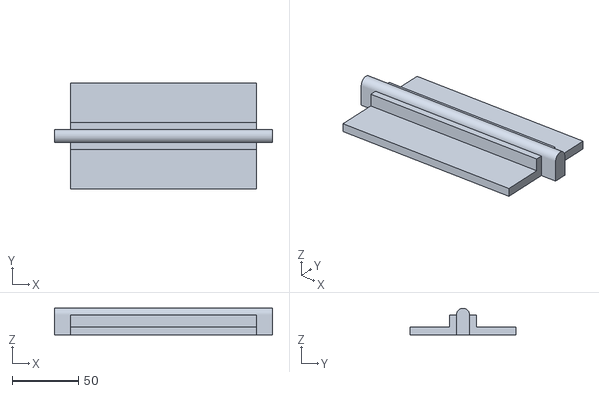
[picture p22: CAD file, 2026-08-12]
CAD_designs/templates/stl's/distance_brackets_template.stl
164.0 x 80.0 x 19.9

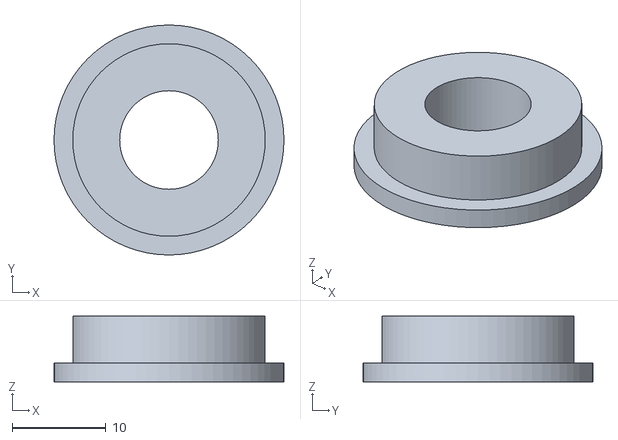
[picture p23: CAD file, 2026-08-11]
CAD_designs/templates/stl's/chassis_beam_drill_template_bushing.stl
24.5 x 24.5 x 7.00

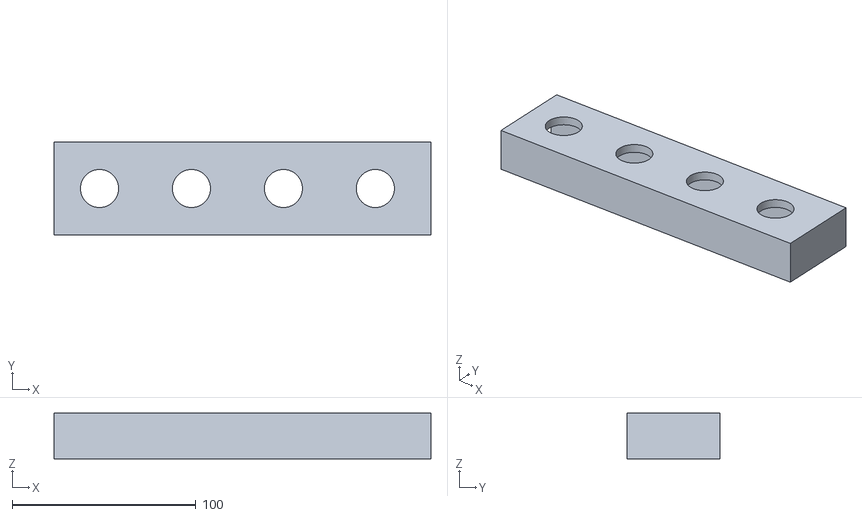
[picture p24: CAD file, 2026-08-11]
CAD_designs/templates/stl's/chassis_beam_drill_template_end_with_bushing.stl
205.0 x 50.5 x 25.0

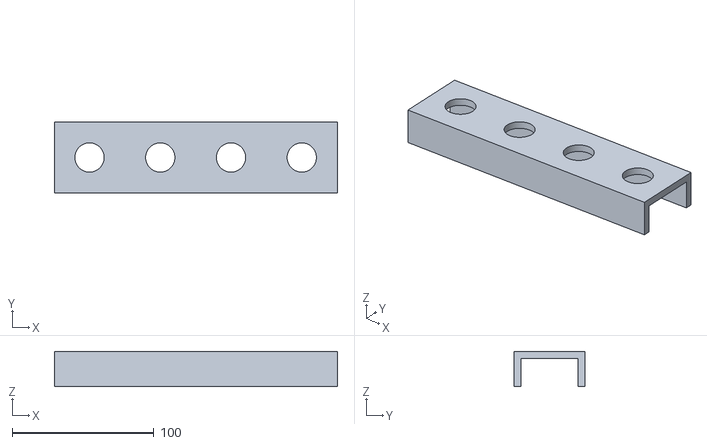
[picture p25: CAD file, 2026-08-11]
CAD_designs/templates/stl's/chassis_beam_drill_template_middle_with_bushing.stl
200.0 x 50.5 x 25.0

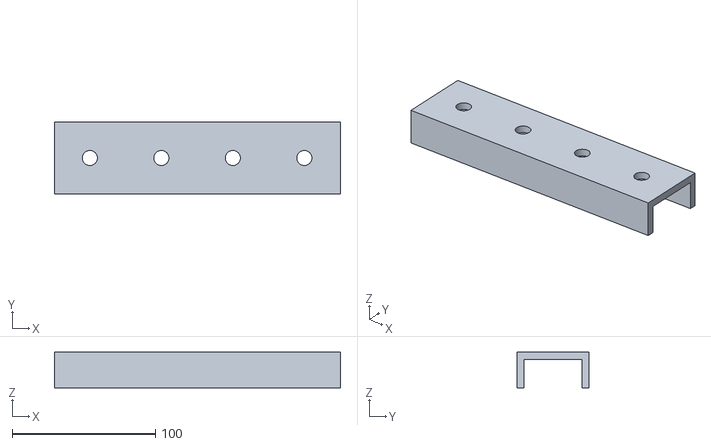
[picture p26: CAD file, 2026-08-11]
CAD_designs/templates/stl's/chassis_beam_drill_template_middle_without_bushing.stl
200.0 x 50.5 x 25.0

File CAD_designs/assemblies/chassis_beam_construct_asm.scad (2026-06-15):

include <../config/parameters.scad>
use <../parts/bracket_top_plate.scad>
use <../parts/chassis_beam_1.scad>
use <../parts/chassis_beam_2.scad>

module chassis_beam_construct_asm(
    toon_brackets = false, 
    toon_onderste_balken = true, 
    toon_bovenste_balken = true
) {
    // Z-hoogtes berekenen zodat de delen netjes op elkaar stapelen
    z_bracket_top = bracket_thick / 2;
    z_bottom_beams = z_bracket_top + (beam_profile / 2);
    z_top_beams = z_bottom_beams + beam_profile;

    // 1. Plaats de 4 bracket_top_plates direct op de hoeken
    if (toon_brackets) {
        for (x = [-chassis_width/2, chassis_width/2]) {
            for (y = [-chassis_length/2, chassis_length/2]) {
                translate([x, y, 0])
                    color("darkgray") 
                    bracket_top_plate();
            }
        }
    }

    // 2. Plaats de 4 onderste balken (Breedte / X-as)
    if (toon_onderste_balken) {
        for (y_center = [-chassis_length/2, chassis_length/2]) {
            for (y_offset = [-bracket_top_hole_dist_y/2, bracket_top_hole_dist_y/2]) {
                translate([0, y_center + y_offset, z_bottom_beams])
                    color("silver")
                    chassis_beam_1(); 
            }
        }
    }

    // 3. Plaats de 4 bovenste balken (Lengterichting / Y-as)
    if (toon_bovenste_balken) {
        for (x_center = [-chassis_width/2, chassis_width/2]) {
            for (x_offset = [-bracket_top_hole_dist_x/2, bracket_top_hole_dist_x/2]) {
                translate([x_center + x_offset, 0, z_top_beams])
                    rotate([0, 0, 90])
                    color("dimgray")
                    chassis_beam_2(); 
            }
        }
    }
}

// Previews
chassis_beam_construct_asm();

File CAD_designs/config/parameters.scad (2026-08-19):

// Global Chassis Dimensions
chassis_width = 750; //kies een veelvoud van 50  
chassis_length = 1000; //kies een veelvoud van 50

// --- Modulair Gatenpatroon (Grid) ---
grid_step = 50; // Universele stapgrootte voor alle gaten

// bolt diameters
m12_bolt_diameter = 12.4; //dikte van de gaten van m12 bout
m10_bolt_diameter = 10.4; //dikte van de gaten van m10 bout
m8_bolt_diameter = 8.4; //dikte van de gaten van m8 bout  
m6_bolt_diameter = 6.4; //dikte van de gaten van m6 bout  


// --- Bereiken (Ranges) voor de Robot Afmetingen ---
// Bereik voor de BREEDTE 
chassis_width_min = 350;
chassis_width_max = 850;

// Bereik voor de LENGTE 
chassis_length_min = 700;
chassis_length_max = 1100;

// Bereik voor de BASE PLATE 
base_length_min = 800;
base_length_max = 1300;

// Beam Profile (Purchased Part)
beam_profile = 40;
beam_thickness = 2;    
beam_length_1 = 1000;
beam_length_2 = 1300;

// Upright & Cover
base_plate_length = 1300;
connect_plate_thick = 5; 
upright_height = 500;
top_side_width = 60;
cover_thick = 5;
cover_clearance = 10;  
cover_overlap = 10;
cover_total_height = 530; 
hole_distance_cover = 30;

// Resolution & Preview
$fn = 60; 
exploded_view = false; 
explosion_dist = 800; 

// Motor & Wheel Data
tire_dia = 430;
tire_width = 100;
hub_dia = 160;
hub_width = 140; //specs from Quinder are: Fork width for mounting: 138mm
axle_dia = 10.2; //specs from Quinder are: Mounting hole: max 10.2mm, zou iets strakker mogen naar 10.1mm, 10.2 nog wat spelling
bolt_dia = 14.2;

// Bracket Geometry universal
bracket_thick = 4;
bracket_bolt_diameter = 10.4; //dikte van de gaten van gaten van de wiel_bracket  
bracket_m8_bolt_diameter = 8.4; //dikte van de gaten van m8 bout  
tire_clearance = 130;      
side_plate_top_width = 240;
side_plate_width = 240;

//Side plate
axle_bottom_dist = 35;
extra_space_bracket = 40;
side_hole_start_from_bottom = 20; 
side_hole_pitch = 100; 

tab_length = 40;         // Lengte van de nok/sleuf
tab_offset_y = 40;       // Positie vanaf het midden over de Y-as (uit elkaar)
laser_tolerance = 1.0;   // Extra snijspeling zodat het makkelijk in elkaar schuift

//top plate
bracket_top_hole_dist_x = 100; // De totale gewenste afstand over de X-as veelvoud van 50 maken
bracket_top_hole_dist_y = 150; // De totale gewenste afstand over de Y-as veelvoud van 50 maken
bracket_top_hole_distance_centrum_holes = 50; //De afstand van centrum gat tot centrum gat in het hart

arm_height = (tire_dia / 2) + tire_clearance;
inner_width = hub_width;
bracket_total_width = inner_width + (extra_space_bracket*2) + (2 * bracket_thick);
bracket_top_z = arm_height + bracket_thick;

// Axle bracket
axle_hex_width = 110;          
axle_hex_height = 40;
axle_hex_straight_part = 30;   
axle_bracket_thickness = 4;    

axle_hole_diameter = 10.3; //Dikte van het gaten in de axle_bracket
axle_hole_distance = 40; //hoogte vanaf de onderkant tot de wiel ophanging

axle_flat_width = axle_dia; // Gebruikt 10.3 uit parameters 
axle_round_dia = bolt_dia;  // Gebruikt 14.2 uit parameters

// --- Caster Wheel Parameters ---  
bracket_width            = 80;  
bracket_thickness        = 4;
caster_wheel_axle_width  = 130;   
caster_wheel_axle_diameter = 20;
bracket_axle_hole_diameter = 10.4;

pivot_cylinder_dia       = 30;  
pivot_cylinder_height    = 100;  

outer_cylinder_thickness = 5;   
outer_cylinder_height    = 60;  
outer_cylinder_z_offset  = 33;   
kap_speling              = 1;   

tube_width               = 35;  
tube_thickness           = 2;   
tube_length              = 400;
tube_length_min          = 240;

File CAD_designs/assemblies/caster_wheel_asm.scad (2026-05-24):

// --- Show/Hide Toggles ---
show_wheel           = true;
show_bracket         = true;
show_pivot           = true; 
show_outer_cylinder  = true; 
show_horizontal_tube = true;
show_axle            = true; // Nieuwe toggle voor de as

use <../parts/caster_wheel_bracket.scad>
use <../parts/caster_wheel_pivot_cilinder.scad>
use <../parts/caster_wheel_outer_cilinder.scad>
use <../parts/caster_wheel_beam.scad>
use <../parts/caster_wheel_axle.scad>

include <../config/parameters.scad>

module caster_wheel_asm() {
    if (show_wheel) {
        color("#333333") {
            import("../imports/wheelbarrow_wheel_4.8_4.00-8.stl", convexity=3);
        }
    }

    // --- Toevoeging: De As ---
    if (show_axle) {
        rotate([0, 0, 90])
        caster_wheel_axle(); 
    }

    if (show_bracket) {
        caster_wheel_bracket();
    }

    top_surface_z = (tire_dia / 2) + tire_clearance + bracket_thickness;
    
    if (show_pivot) {
        pivot_z_center = top_surface_z + (pivot_cylinder_height / 2);
        translate([0, 0, pivot_z_center])
            caster_wheel_pivot_cilinder();
    }
    
    outer_z_center = top_surface_z + outer_cylinder_z_offset + (outer_cylinder_height / 2);
    
    if (show_outer_cylinder) {
        translate([0, 0, outer_z_center])
            caster_wheel_outer_cilinder();
    }
    
    if (show_horizontal_tube) {
        translate([0, tube_length / 2, outer_z_center])
            rotate([0, 0, 90])
                caster_wheel_beam();
    }
}

caster_wheel_asm();

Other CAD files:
CAD_designs/templates/stl's/chassis_beam_drill_template_end_without_bushing.stl
CAD_designs/templates/stl's/axle_bracket_drill_template.stl
CAD_designs/assemblies/wheel_unit_asm.scad
CAD_designs/accesories/Daheng_camera/va_imaging_camera_mount.scad
CAD_designs/accesories/USB2CAN innomaker/USB2CAN converter Innomaker clamp.scad
CAD_designs/assemblies/chassis_frame_asm.scad
CAD_designs/exports/drill_jigs_3d_print.scad
CAD_designs/exports/nesting_laser_cut.scad
CAD_designs/main_assembly_2wd.scad
CAD_designs/main_assembly_4wd.scad
CAD_designs/older_models/Bruut_OpenAgbot.scad
CAD_designs/older_models/Bruut_OpenAgbot_3D_printable.scad
CAD_designs/parts/axle_bracket.scad
CAD_designs/parts/bracket_side_plate.scad
CAD_designs/parts/bracket_top_plate.scad
CAD_designs/parts/caster_wheel_axle.scad
CAD_designs/parts/caster_wheel_beam.scad
CAD_designs/parts/caster_wheel_bracket.scad
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

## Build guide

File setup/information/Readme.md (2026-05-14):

draden van de controller naar de gashendel

Rood = +5V
Wit = GND
Blauw = signaal (0.8–3.5V)
(moet worden gecheckt)

rood wit is verschil +-5 volt (specs gelezen)
bij test geven rood  - wit 4.36 volt

blauw wit +-0.8 volt of volgas 3.5 volt (specs gelezen)
bij test geven onderling wit - blauw voltage van 0.8 tot 3.5
Bij uit geeft de 0.8 volt en bij volgas geeft die 3.5 voltage
Er is geen verschil tussen de standen low, mid en high

Arduino dac waardes code bij (DAC waarden op basis van 12-bit resolutie: 0-4095)
analogWrite(A0, 700); = 0.77 volt
analogWrite(A0, 2500); = 2.8 volt 
analogWrite(A0, 3100); = 3.4 volt

De draden zijn zo verbonden

Rood gaat gewoon naar de controller toe, blijft heel
Blauw is het signaaldraad deze gaat naar de A0 draad van de arduino
Wit is het GND draad deze gaat naar de GND van de arduino

Draden van de handgas naar de controller
Rood = 5 volt draad uit test 4.36V = heel laten gaat niet naar de arduino
Blauw = signaaldraad (0.8–3.5V) = A0 arduino
Wit = GND = GND arduino
zwart
oranje
bruin
groen
geel

Draden van de vooruit achteruit naar de controller
rood
geel
lichtblauw
groen

De DAC module MCP4728
Met de DAC Module worden onafhankelijk voor het linker en rechterwiel via het signaal draad blauw en het witte GND nageboots.
Hier is het complete en overzichtelijke aansluitschema voor je Arduino, de MCP4728 DAC-module en de motorcontrollers van de wielen.

1. Arduino ➔ MCP4728 DAC-module (I2C Communicatie)

Dit is de verbinding om de module van stroom te voorzien en de data (de commando's vanuit Python) door te geven. Je gebruikt de pinnen aan de onderkant van het bordje (waar SDA en SCL bij staan):

    Arduino 5V ➔ VCC (of VDD) op de DAC-module
    Arduino GND ➔ GND op de DAC-module
    Arduino SCL (A5) ➔ SCL op de DAC-module (Kloksignaal)
    Arduino SDA (A4) ➔ SDA op de DAC-module (Datasignaal)

2. MCP4728 DAC-module ➔ Motorcontrollers (Het Signaal)
Dit is de verbinding die de analoge spanning (0.77V - 3.4V) naar de motoren stuurt, ter vervanging van de fysieke gashendel. Je gebruikt de uitgangen aan de bovenkant (VA, VB, etc.):

    VA (Kanaal A) ➔ Blauwe signaaldraad van het Linker wiel
    VB (Kanaal B) ➔ Blauwe signaaldraad van het Rechter wiel
    GND ➔ Witte GND-draad van BEIDE wielen

Gebruik maken van de UBX informatie ipv de NEMEA berichten 

IMU BNO086

IMU 3V3 ➔ 3.3V Power      ➔ pin 1 on the JETSON 
IMU SDA ➔ I2C SDA (Data)  ➔ pin 3 on the JETSON
IMU SCL ➔ I2C SCL (Clock) ➔ pin 5 on the JETSON
IMU GND ➔ Ground          ➔ pin 6 on the JETSON

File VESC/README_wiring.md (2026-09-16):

# Motor wiring: Quinder 8" hub motor → VESC Classic 100V

Quinder 8" 48 V 550 W (10101025). Motor cable: 3 × 2.5 mm² + 8 × 0.14 mm², 200 mm.

> **Blue, green and yellow are in the cable twice.** Sort by thickness, not by colour:
> **2.5 mm² = phase, 0.14 mm² = hall.** 48 V on a hall wire kills the sensors inside the hub.

## Connect these 8 wires

```text
MOTOR                        VESC CLASSIC 100V

Phase, 2.5 mm²               Phase bullets, 5.5 mm
  blue   ─────────────────── U
  green  ─────────────────── V
  yellow ─────────────────── W

Hall, 0.14 mm²               SENSORS, 6-pin JST-GH 1.25 mm
  red    ─────────────────── pin 6  +5V
                             pin 5  TEMP  (leave empty)
  blue   ─────────────────── pin 4  H1
  green  ─────────────────── pin 3  H2
  yellow ─────────────────── pin 2  H3
  black  ─────────────────── pin 1  GND

Not connected, 0.14 mm²
  white, purple, orange: insulate each one separately and label it
```

**SENSORS pin numbers:** count from the pin 1 mark on the PCB, not from the direction the printed labels read.

## What the 8 thin wires do

The five hall wires tell the VESC where the rotor is, so it can start and run smoothly at low speed.

| Wire | Function |
|---|---|
| Red | Hall supply + |
| Black  | Hall supply − (ground) |
| Blue | Hall signal A |
| Green  | Hall signal B |
| Yellow | Hall signal C |
| White  | Speed pulse, 6 per revolution. *Not connected*: the VESC gets speed from the halls. |
| Purple | Motor temperature, 3-level active output (4.8 → 0.67 V), warning at 105 °C, cut-off at 110 °C. *Not connected.* |
| Orange | Not in the motor spec. *Not connected*: unknown, measure it before you cut it off. |

- **Red on +5V, black on GND.** Swapping these two destroys the hall sensors.
- The hall signal order on H1–H3 doesn't matter: hall detection in VESC Tool works it out.
- Purple is an active output, not an NTC, so it can't go on TEMP pin 5.

## 3-phase wiring

- Blue, green, yellow (phase A, B, C) → U, V, W, on 5.5 mm bullets, each in its own heat shrink.
- Phase order only decides which way the wheel turns. Runs backwards? Swap any two phase wires and re-run detection, or use *Invert Motor Direction*. Don't swap hall wires for this.
- 2.5 mm² is enough for the motor's 20 A max. The lead is only 200 mm, so extend it with 2.5 mm² or thicker.
- Route the hall wires away from the phase wires: twisted, crossing at right angles.

## VESC Tool

- *Sensor Port Mode*: **Hall**
- *Motor Temp Sensor*: **Disabled** (purple is not connected)
- *Motor Current Max*: **15 A**. Without purple there is no motor over-temperature protection, so this limit is all you have.

---

Sources: Quinder 8" 48V spec (ver. 2024-01A), VESC Classic 100V datasheet (rev. April 2026, table 2).

Full Dutch version with background: [quinder_motor_bedrading.html](quinder_motor_bedrading.html)

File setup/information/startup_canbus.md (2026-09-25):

# Startup CAN-bus

Op de Orin Nano (robot-PC) moet de CAN-bus na elke reboot of na het los- en vastmaken van de adapter opnieuw worden geactiveerd.

## Welke interface?

| Interface | Wat |
|---|-----|
| `can0` | Interne CAN-controller van de Jetson (mttcan). Niet gebruiken voor de VESC's. |
| `can1` | InnoMaker USB2CAN-adapter. Hier hangen de VESC's aan (ID 1 links, ID 2 rechts). |

De app gebruikt `can_channel: "can1"` (zie `data/config.example.json`).

## Activeren

```bash
sudo ip link set can1 down && sudo ip link set can1 type can bitrate 500000 loopback off && sudo ip link set can1 up
```

## Controleren

Staat de interface online en zijn er geen bus-fouten?

```bash
ip link show can1
```

Sturen de VESC's frames? (VESC's moeten aan staan.)

```bash
candump can1
```

## Problemen

- **Geen frames / BUS-OFF:** controleer dat de VESC's aan staan, dat de bitrate 500000 is en dat de bus aan beide uiteinden een 120 Ω-afsluiting heeft. Voer daarna de `down`/`up`-stappen hierboven opnieuw uit.
- **`can1` bestaat niet:** adapter niet herkend. Controleer de USB-kabel en `ip link`.
- **Oude scripts noemen `can0`:** `VESC/vesc_slider_2_wheels.py` heeft `can0` in de header. Op deze machine moet dat `can1` zijn.

## Automatisch bij opstarten (optioneel)

Nog niet ingesteld. Kan met een systemd-service of udev-regel die bovenstaand commando uitvoert zodra `can1` verschijnt.

Zie ook: `innomaker_usb2can_jetson_setup.json` en `VESC/README_DEV.md`.

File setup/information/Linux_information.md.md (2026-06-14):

finding the Linux connected boards

command ls /dev/ttyACM* 

Wanneer permission denied geef jezelf toegang tot de poort 

sudo usermod -a -G dialout $USER

of geforceerd open zetten

sudo chmod 666 /dev/ttyACM1

inplaats van python roep je in linux/ubuntu python3 op

sh: 1: vite: Permission denied *fix*
chmod -R +x node_modules/.bin

Vinden van de USB poorten op de jetson 
 ls /dev/ttyACM* /dev/ttyUSB*

ls -l /dev/serial/by-id/

ls -l /dev/ttyACM*

udevadm info -n /dev/ttyACM3 | grep ID_MODEL_ID

Of de hele tekst

jetson@jetson-desktop:~$ ls -l /dev/ttyACM*
crw-rw---- 1 root dialout 166, 0 jun  4 23:46 /dev/ttyACM0
crw-rw---- 1 root dialout 166, 1 jan  1  1970 /dev/ttyACM1
crw-rw---- 1 root dialout 166, 2 jan  1  1970 /dev/ttyACM2
crw-rw---- 1 root dialout 166, 3 jun  5 09:39 /dev/ttyACM3
jetson@jetson-desktop:~$ udevadm info -n /dev/ttyACM0 | grep ID_MODEL_ID
E: ID_MODEL_ID=01ab
jetson@jetson-desktop:~$ udevadm info -n /dev/ttyACM1 | grep ID_MODEL_ID
E: ID_MODEL_ID=01a9
jetson@jetson-desktop:~$ udevadm info -n /dev/ttyACM21 | grep ID_MODEL_ID
Unknown device "/dev/ttyACM21": No such file or directory
jetson@jetson-desktop:~$ udevadm info -n /dev/ttyACM2 | grep ID_MODEL_ID
E: ID_MODEL_ID=1002
jetson@jetson-desktop:~$ udevadm info -n /dev/ttyACM3 | grep ID_MODEL_ID
E: ID_MODEL_ID=0069
jetson@jetson-desktop:~$ ls -l /dev/serial/by-id/
total 0
lrwxrwxrwx 1 root root 13 jun  5 09:39 usb-Arduino_UNO_R4_Minima_320B2D1839313139DD3033354B57336E-if00 -> ../../ttyACM3
lrwxrwxrwx 1 root root 13 jan  1  1970 usb-Arduino_UNO_WiFi_R4_CMSIS-DAP_F412FA75D878-if01 -> ../../ttyACM2
lrwxrwxrwx 1 root root 13 jan  1  1970 usb-u-blox_AG_-_www.u-blox.com_u-blox_GNSS_receiver-if00 -> ../../ttyACM0
jetson@jetson-desktop:~$ ls -l /dev/ttyACM*      
*

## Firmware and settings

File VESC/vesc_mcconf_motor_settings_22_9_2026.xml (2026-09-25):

<?xml version="1.0" encoding="UTF-8"?>
<MCConfiguration>
    <ConfigVersion>4</ConfigVersion>
    <pwm_mode>1</pwm_mode>
    <comm_mode>0</comm_mode>
    <motor_type>2</motor_type>
    <sensor_mode>0</sensor_mode>
    <l_current_max>20</l_current_max>
    <l_current_min>-10</l_current_min>
    <l_in_current_max>20</l_in_current_max>
    <l_in_current_min>-3</l_in_current_min>
    <l_in_current_map_start>1</l_in_current_map_start>
    <l_in_current_map_filter>0.005</l_in_current_map_filter>
    <l_abs_current_max>25</l_abs_current_max>
    <l_min_erpm>-3700</l_min_erpm>
    <l_max_erpm>3700</l_max_erpm>
    <l_erpm_start>0.8</l_erpm_start>
    <l_max_erpm_fbrake>300</l_max_erpm_fbrake>
    <l_max_erpm_fbrake_cc>1500</l_max_erpm_fbrake_cc>
    <l_min_vin>14</l_min_vin>
    <l_max_vin>65</l_max_vin>
    <l_battery_cut_start>42</l_battery_cut_start>
    <l_battery_cut_end>40</l_battery_cut_end>
    <l_battery_regen_cut_start>56</l_battery_regen_cut_start>
    <l_battery_regen_cut_end>57.5</l_battery_regen_cut_end>
    <l_slow_abs_current>0</l_slow_abs_current>
    <l_temp_fet_start>85</l_temp_fet_start>
    <l_temp_fet_end>100</l_temp_fet_end>
    <l_temp_motor_start>85</l_temp_motor_start>
    <l_temp_motor_end>100</l_temp_motor_end>
    <l_temp_accel_dec>0.14</l_temp_accel_dec>
    <l_min_duty>0.005</l_min_duty>
    <l_max_duty>0.95</l_max_duty>
    <l_watt_max>1.5e+06</l_watt_max>
    <l_watt_min>-1.5e+06</l_watt_min>
    <l_current_max_scale>1</l_current_max_scale>
    <l_current_min_scale>1</l_current_min_scale>
    <l_duty_start>1</l_duty_start>
    <l_additional_faults>0</l_additional_faults>
    <sl_min_erpm>150</sl_min_erpm>
    <sl_min_erpm_cycle_int_limit>1100</sl_min_erpm_cycle_int_limit>
    <sl_max_fullbreak_current_dir_change>10</sl_max_fullbreak_current_dir_change>
    <sl_cycle_int_limit>62</sl_cycle_int_limit>
    <sl_phase_advance_at_br>0.8</sl_phase_advance_at_br>
    <sl_cycle_int_rpm_br>80000</sl_cycle_int_rpm_br>
    <sl_bemf_coupling_k>600</sl_bemf_coupling_k>
    <hall_table__0>-1</hall_table__0>
    <hall_table__1>1</hall_table__1>
    <hall_table__2>3</hall_table__2>
    <hall_table__3>2</hall_table__3>
    <hall_table__4>5</hall_table__4>
    <hall_table__5>6</hall_table__5>
    <hall_table__6>4</hall_table__6>
    <hall_table__7>-1</hall_table__7>
    <hall_sl_erpm>2000</hall_sl_erpm>
    <foc_current_kp>1.8194</foc_current_kp>
    <foc_current_ki>682.76</foc_current_ki>
    <foc_f_zv>30000</foc_f_zv>
    <foc_dt_us>0.12</foc_dt_us>
    <foc_encoder_inverted>0</foc_encoder_inverted>
    <foc_encoder_offset>180</foc_encoder_offset>
    <foc_encoder_ratio>7</foc_encoder_ratio>
    <foc_sensor_mode>2</foc_sensor_mode>
    <foc_pll_kp>2000</foc_pll_kp>
    <foc_pll_ki>30000</foc_pll_ki>
    <foc_motor_l>0.00090972</foc_motor_l>
    <foc_motor_ld_lq_diff>0.00014108</foc_motor_ld_lq_diff>
    <foc_motor_r>0.3414</foc_motor_r>
    <foc_motor_flux_linkage>0.055617</foc_motor_flux_linkage>
    <foc_observer_gain>320000</foc_observer_gain>
    <foc_observer_gain_slow>0.05</foc_observer_gain_slow>
    <foc_observer_offset>-1</foc_observer_offset>
    <foc_duty_dowmramp_kp>50</foc_duty_dowmramp_kp>
    <foc_duty_dowmramp_ki>1000</foc_duty_dowmramp_ki>
    <foc_start_curr_dec>1</foc_start_curr_dec>
    <foc_start_curr_dec_rpm>2500</foc_start_curr_dec_rpm>
    <foc_openloop_rpm>1500</foc_openloop_rpm>
    <foc_openloop_rpm_low>0</foc_openloop_rpm_low>
    <foc_sl_openloop_hyst>0.1</foc_sl_openloop_hyst>
    <foc_sl_openloop_time_lock>0</foc_sl_openloop_time_lock>
    <foc_sl_openloop_time_ramp>0.1</foc_sl_openloop_time_ramp>
    <foc_sl_openloop_time>0.05</foc_sl_openloop_time>
    <foc_sl_openloop_boost_q>0</foc_sl_openloop_boost_q>
    <foc_sl_openloop_max_q>-1</foc_sl_openloop_max_q>
    <foc_hall_table__0>255</foc_hall_table__0>
    <foc_hall_table__1>165</foc_hall_table__1>
    <foc_hall_table__2>100</foc_hall_table__2>
    <foc_hall_table__3>133</foc_hall_table__3>
    <foc_hall_table__4>33</foc_hall_table__4>
    <foc_hall_table__5>0</foc_hall_table__5>
    <foc_hall_table__6>66</foc_hall_table__6>
    <foc_hall_table__7>255</foc_hall_table__7>
    <foc_hall_interp_erpm>500</foc_hall_interp_erpm>
    <foc_sl_erpm_start>4500</foc_sl_erpm_start>
    <foc_sl_erpm>5000</foc_sl_erpm>
    <foc_control_sample_mode>0</foc_control_sample_mode>
    <foc_current_sample_mode>0</foc_current_sample_mode>
    <foc_sat_comp_mode>2</foc_sat_comp_mode>
    <foc_sat_comp>0</foc_sat_comp>
    <foc_temp_comp>0</foc_temp_comp>
    <foc_temp_comp_base_temp>25</foc_temp_comp_base_temp>
    <foc_current_filter_const>0.1</foc_current_filter_const>
    <foc_cc_decoupling>0</foc_cc_decoupling>
    <foc_observer_type>3</foc_observer_type>
    <foc_hfi_amb_mode>0</foc_hfi_amb_mode>
    <foc_hfi_amb_current>60</foc_hfi_amb_current>
    <foc_hfi_amb_tres>15</foc_hfi_amb_tres>
    <foc_hfi_voltage_start>20</foc_hfi_voltage_start>
    <foc_hfi_voltage_run>4</foc_hfi_voltage_run>
    <foc_hfi_voltage_max>6</foc_hfi_voltage_max>
    <foc_hfi_gain>0.3</foc_hfi_gain>
    <foc_hfi_max_err>0.15</foc_hfi_max_err>
    <foc_hfi_hyst>0</foc_hfi_hyst>
    <foc_sl_erpm_hfi>3000</foc_sl_erpm_hfi>
    <foc_hfi_reset_erpm>500</foc_hfi_reset_erpm>
    <foc_hfi_start_samples>5</foc_hfi_start_samples>
    <foc_hfi_obs_ovr_sec>0.001</foc_hfi_obs_ovr_sec>
    <foc_hfi_samples>1</foc_hfi_samples>
    <foc_offsets_cal_mode>1</foc_offsets_cal_mode>
    <foc_offsets_current__0>2053.36</foc_offsets_current__0>
    <foc_offsets_current__1>2053.21</foc_offsets_current__1>
    <foc_offsets_current__2>2052.74</foc_offsets_current__2>
    <foc_offsets_voltage__0>0.0018</foc_offsets_voltage__0>
    <foc_offsets_voltage__1>0.0024</foc_offsets_voltage__1>
    <foc_offsets_voltage__2>-0.0042</foc_offsets_voltage__2>
    <foc_offsets_voltage_undriven__0>0</foc_offsets_voltage_undriven__0>
    <foc_offsets_voltage_undriven__1>0</foc_offsets_voltage_undriven__1>
    <foc_offsets_voltage_undriven__2>0</foc_offsets_voltage_undriven__2>
    <foc_phase_filter_enable>1</foc_phase_filter_enable>
    <foc_phase_filter_disable_fault>1</foc_phase_filter_disable_fault>
    <foc_phase_filter_max_erpm>4000</foc_phase_filter_max_erpm>
    <foc_mtpa_mode>0</foc_mtpa_mode>
    <foc_fw_current_max>0</foc_fw_current_max>
    <foc_fw_duty_start>0.9</foc_fw_duty_start>
    <foc_fw_q_current_factor>0.02</foc_fw_q_current_factor>
    <foc_fw_backoff>1</foc_fw_backoff>
    <foc_fw_ramp_time>0.2</foc_fw_ramp_time>
    <foc_speed_soure>0</foc_speed_soure>
    <foc_short_ls_on_zero_duty>0</foc_short_ls_on_zero_duty>
    <foc_overmod_factor>1</foc_overmod_factor>
    <foc_mag_vd_max>0.98</foc_mag_vd_max>
    <sp_pid_loop_rate>5</sp_pid_loop_rate>
    <s_pid_kp>0.004</s_pid_kp>
    <s_pid_ki>0.004</s_pid_ki>
    <s_pid_kd>0.0001</s_pid_kd>
    <s_pid_kd_filter>0.2</s_pid_kd_filter>
    <s_pid_min_erpm>900</s_pid_min_erpm>
    <s_pid_allow_braking>1</s_pid_allow_braking>
    <s_pid_ramp_erpms_s>25000</s_pid_ramp_erpms_s>
    <s_pid_speed_source>0</s_pid_speed_source>
    <p_pid_kp>0.025</p_pid_kp>
    <p_pid_ki>0</p_pid_ki>
    <p_pid_kd>0</p_pid_kd>
    <p_pid_offset>0</p_pid_offset>
    <p_pid_kd_proc>0.00035</p_pid_kd_proc>
    <p_pid_kd_filter>0.2</p_pid_kd_filter>
    <p_pid_ang_div>1</p_pid_ang_div>
    <p_pid_gain_dec_angle>0</p_pid_gain_dec_angle>
    <cc_startup_boost_duty>0.01</cc_startup_boost_duty>
    <cc_min_current>0.05</cc_min_current>
    <cc_gain>0.0046</cc_gain>
    <cc_ramp_step_max>0.04</cc_ramp_step_max>
    <m_fault_stop_time_ms>500</m_fault_stop_time_ms>
    <m_duty_ramp_step>0.02</m_duty_ramp_step>
    <m_current_backoff_gain>0.5</m_current_backoff_gain>
    <m_encoder_counts>8192</m_encoder_counts>
    <m_encoder_sin_amp>1</m_encoder_sin_amp>
    <m_encoder_cos_amp>1</m_encoder_cos_amp>
    <m_encoder_sin_offset>1.65</m_encoder_sin_offset>
    <m_encoder_cos_offset>1.65</m_encoder_cos_offset>
    <m_encoder_sincos_filter_constant>0.5</m_encoder_sincos_filter_constant>
    <m_encoder_sincos_phase_correction>0</m_encoder_sincos_phase_correction>
    <m_sensor_port_mode>0</m_sensor_port_mode>
    <m_invert_direction>1</m_invert_direction>
    <m_drv8301_oc_mode>0</m_drv8301_oc_mode>
    <m_drv8301_oc_adj>19</m_drv8301_oc_adj>
    <m_bldc_f_sw_min>3000</m_bldc_f_sw_min>
    <m_bldc_f_sw_max>35000</m_bldc_f_sw_max>
    <m_dc_f_sw>25000</m_dc_f_sw>
    <m_ntc_motor_beta>3380</m_ntc_motor_beta>
    <m_out_aux_mode>0</m_out_aux_mode>
    <m_motor_temp_sens_type>8</m_motor_temp_sens_type>
    <m_ptc_motor_coeff>0.61</m_ptc_motor_coeff>
    <m_ntcx_ptcx_res>10000</m_ntcx_ptcx_res>
    <m_ntcx_ptcx_temp_base>25</m_ntcx_ptcx_temp_base>
    <m_hall_extra_samples>3</m_hall_extra_samples>
    <m_batt_filter_const>45</m_batt_filter_const>
    <si_motor_poles>14</si_motor_poles>
    <si_gear_ratio>3</si_gear_ratio>
    <si_wheel_diameter>0.083</si_wheel_diameter>
    <si_battery_type>0</si_battery_type>
    <si_battery_cells>3</si_battery_cells>
    <si_battery_ah>6</si_battery_ah>
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

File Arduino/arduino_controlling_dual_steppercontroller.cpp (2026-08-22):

/*
 * OpenAgbot - Stuurcontroller voor TWEE gestuurde voorwielen
 * -----------------------------------------------------------
 * Board   : Arduino UNO R4 Minima
 * Drivers : 2x HBS86H (closed loop) + NEMA 34 met 5:1 tandwielkast
 * Pinnen  : zie setup/information/steppermotor_information.json
 *
 * Bedrading per driver: PUL+/DIR+/ENA+ op de Arduino pin,
 * PUL-/DIR-/ENA- van BEIDE drivers samen op Arduino GND.
 * De 48V-min blijft gescheiden (de driver-ingangen zijn opto-geisoleerd).
 *
 * D0/D1 blijven bewust vrij: dat is Serial1 (UART), handig voor debug.
 * De Jetson praat via USB, dat is de aparte `Serial` poort.
 *
 * Alle communicatie is regelgebaseerd ASCII. Elk commando geeft precies een
 * antwoordregel terug, zodat de Python-kant altijd kan synchroniseren.
 * Het volledige protocol staat in steppermotor_information.json.
 */

#include <Arduino.h>

// ---------------------------------------------------------------------------
// Pinnen
// ---------------------------------------------------------------------------
#define LEFT_PUL_PIN   2
#define LEFT_DIR_PIN   3
#define LEFT_ENA_PIN   4

#define RIGHT_PUL_PIN  5
#define RIGHT_DIR_PIN  6
#define RIGHT_ENA_PIN  7

// ---------------------------------------------------------------------------
// Mechanische constanten
// ---------------------------------------------------------------------------
const float STEPS_PER_REV    = 3200.0;                               // microstappen per motoromwenteling
const float GEAR_RATIO       = 5.0;                                  // tandwielkast
const float STEPS_PER_DEGREE = (STEPS_PER_REV * GEAR_RATIO) / 360.0; // 44.444 stappen per graad

// Timing die de HBS86H nodig heeft
const unsigned int PULSE_WIDTH_US = 5;  // breedte van de PUL puls
const unsigned int DIR_SETUP_US   = 5;  // rusttijd na een richtingswissel, voor de eerstvolgende puls

// ---------------------------------------------------------------------------
// Instelbaar via serieel (V: en M:)
// ---------------------------------------------------------------------------
unsigned long minStepDelayUs   = 300;   // hoogste snelheid. Lager = sneller (kijk uit i.v.m. stallen)
unsigned long startStepDelayUs = 1200;  // startsnelheid van de acceleratieramp
long          rampSteps        = 400;   // aantal stappen om op te trekken / af te remmen (0 = geen ramp)
float         maxAngleDeg      = 50.0;  // softwarelimiet op de stuuruitslag, gelijk aan config.json

// ---------------------------------------------------------------------------
// Motorstructuur
// ---------------------------------------------------------------------------
struct Stepper {
  uint8_t       pulPin;
  uint8_t       dirPin;
  uint8_t       enaPin;
  long          currentSteps;
  long          targetSteps;
  unsigned long lastStepMicros;
  long          stepsIntoMove;   // teller voor de acceleratieramp
  int8_t        lastDir;         // -1, 0 of +1; 0 betekent nog niet gezet
  bool          enabled;
};

const uint8_t MOTOR_COUNT = 2;
const uint8_t LEFT  = 0;
const uint8_t RIGHT = 1;

Stepper motors[MOTOR_COUNT] = {
  { LEFT_PUL_PIN,  LEFT_DIR_PIN,  LEFT_ENA_PIN,  0, 0, 0, 0, 0, true },  // index 0 = linker voorwiel
  { RIGHT_PUL_PIN, RIGHT_DIR_PIN, RIGHT_ENA_PIN, 0, 0, 0, 0, 0, true }   // index 1 = rechter voorwiel
};

// ---------------------------------------------------------------------------
// Seriele regelbuffer
// ---------------------------------------------------------------------------
char    lineBuf[80];
uint8_t lineLen      = 0;
bool    lineOverflow = false;

// ---------------------------------------------------------------------------
// Hulpfuncties
// ---------------------------------------------------------------------------
long degreesToSteps(float degrees) {
  return (long)lround(degrees * STEPS_PER_DEGREE);
}

float stepsToDegrees(long steps) {
  return (float)steps / STEPS_PER_DEGREE;
}

void setEnabled(Stepper &m, bool on) {
  // Bij de HBS86H betekent LOW op ENA dat de driver AAN staat (as vastgehouden).
  digitalWrite(m.enaPin, on ? LOW : HIGH);
  m.enabled = on;
  if (on) {
    // Voorkom dat de motor bij het vastzetten alsnog naar een oud doel schiet:
    // na handmatig verdraaien klopt die oude target niet meer.
    m.targetSteps    = m.currentSteps;
    m.stepsIntoMove  = 0;
    m.lastStepMicros = micros();
  }
}

// Zet een doelhoek. Geeft true terug als de hoek door de limiet is bijgesneden.
bool setTargetDegrees(Stepper &m, float degrees) {
  bool clamped = false;
  if (degrees > maxAngleDeg)       { degrees = maxAngleDeg;  clamped = true; }
  else if (degrees < -maxAngleDeg) { degrees = -maxAngleDeg; clamped = true; }
  m.targetSteps = degreesToSteps(degrees);
  return clamped;
}

void zeroMotor(Stepper &m) {
  m.currentSteps  = 0;
  m.targetSteps   = 0;
  m.stepsIntoMove = 0;
}

// Huidige stapinterval, inclusief lineaire optrek- en afremramp.
unsigned long currentInterval(const Stepper &m) {
  if (rampSteps <= 0) return minStepDelayUs;

  long remaining = labs(m.targetSteps - m.currentSteps);
  // De ramp kijkt naar de kortste van twee: hoe ver we onderweg zijn (optrekken)
  // en hoe ver we nog moeten (afremmen).
  long phase = (m.stepsIntoMove < remaining) ? m.stepsIntoMove : remaining;
  if (phase >= rampSteps) return minStepDelayUs;

  long span = (long)startStepDelayUs - (long)minStepDelayUs;
  if (span <= 0) return minStepDelayUs;
  return (unsigned long)((long)startStepDelayUs - (span * phase) / rampSteps);
}

bool anyMotorMoving() {
  for (uint8_t i = 0; i < MOTOR_COUNT; i++) {
    if (motors[i].enabled && motors[i].currentSteps != motors[i].targetSteps) return true;
  }
  return false;
}

// ---------------------------------------------------------------------------
// Motoraansturing: beide motoren pulsen in dezelfde loop-iteratie, zodat de een
// niet op de ander hoeft te wachten.
// ---------------------------------------------------------------------------
void serviceMotors() {
  unsigned long now    = micros();
  bool          pulsed = false;

  for (uint8_t i = 0; i < MOTOR_COUNT; i++) {
    Stepper &m = motors[i];

    if (!m.enabled) continue;

    if (m.currentSteps == m.targetSteps) {
      m.stepsIntoMove = 0;   // klaar: een volgende beweging begint weer onderaan de ramp
      continue;
    }

    if ((unsigned long)(now - m.lastStepMicros) < currentInterval(m)) continue;

    int8_t dir = (m.currentSteps < m.targetSteps) ? 1 : -1;
    if (dir != m.lastDir) {
      digitalWrite(m.dirPin, dir > 0 ? HIGH : LOW);
      m.lastDir = dir;
      delayMicroseconds(DIR_SETUP_US); // DIR moet stabiel staan voor de PUL flank
    }

    digitalWrite(m.pulPin, HIGH);
    m.lastStepMicros = now;
    m.currentSteps  += dir;
    if (m.stepsIntoMove < 1000000L) m.stepsIntoMove++;
    pulsed = true;
  }

  if (pulsed) {
    delayMicroseconds(PULSE_WIDTH_US);
    for (uint8_t i = 0; i < MOTOR_COUNT; i++) digitalWrite(motors[i].pulPin, LOW);
  }
}

// ---------------------------------------------------------------------------
// Antwoorden
// ---------------------------------------------------------------------------
void printPositions() {
  Serial.print("POS:");
  Serial.print(stepsToDegrees(motors[LEFT].currentSteps), 2);
  Serial.print(",");
  Serial.println(stepsToDegrees(motors[RIGHT].currentSteps), 2);
}

void printStatus() {
  Serial.print("STA:POS=");
  Serial.print(stepsToDegrees(motors[LEFT].currentSteps), 2);
  Serial.print(",");
  Serial.print(stepsToDegrees(motors[RIGHT].currentSteps), 2);
  Serial.print(";TGT=");
  Serial.print(stepsToDegrees(motors[LEFT].targetSteps), 2);
  Serial.print(",");
  Serial.print(stepsToDegrees(motors[RIGHT].targetSteps), 2);
  Serial.print(";EN=");
  Serial.print(motors[LEFT].enabled ? 1 : 0);
  Serial.print(",");
  Serial.print(motors[RIGHT].enabled ? 1 : 0);
  Serial.print(";MOV=");
  Serial.print(anyMotorMoving() ? 1 : 0);
  Serial.print(";LIM=");
  Serial.print(maxAngleDeg, 2);
  Serial.print(";VMIN=");
  Serial.print(minStepDelayUs);
  Serial.print(";VSTART=");
  Serial.print(startStepDelayUs);
  Serial.print(";RAMP=");
  Serial.println(rampSteps);
}

void ackOk(const char* cmd, bool clamped = false) {
  Serial.print("OK:");
  Serial.print(cmd);
  if (clamped) Serial.print(";CLAMPED");
  Serial.println();
}

void ackErr(const char* reason) {
  Serial.print("ERR:");
  Serial.println(reason);
}

// ---------------------------------------------------------------------------
// Commando parsing
// ---------------------------------------------------------------------------
const uint8_t PARSE_ERROR = 0xFF;

// Splitst "1.5,-2.0" op in floats. Geeft PARSE_ERROR bij een ongeldig getal
// of bij meer waarden dan verwacht.
uint8_t parseFloats(char* arg, float* out, uint8_t maxCount) {
  uint8_t n   = 0;
  char*   tok = strtok(arg, ",");
  while (tok != NULL) {
    if (n >= maxCount) return PARSE_ERROR;
    char* end;
    float value = (float)strtod(tok, &end);
    if (end == tok) return PARSE_ERROR;
    out[n++] = value;
    tok = strtok(NULL, ",");
  }
  return n;
}

void processCommand(char* line) {
  // Splits op de dubbele punt
  char* colon = strchr(line, ':');
  if (colon == NULL) { ackErr("NO_COLON"); return; }
  *colon    = '\0';
  char* cmd = line;
  char* arg = colon + 1;

  // Commando naar hoofdletters, zodat "a:10" ook werkt
  for (char* p = cmd; *p; p++) *p = toupper(*p);

  float   values[3];
  uint8_t count;

  // ---- Stuurhoek zetten -------------------------------------------------
  if (strcmp(cmd, "A") == 0) {
    count = parseFloats(arg, values, 2);
    if (count == PARSE_ERROR || count == 0) { ackErr("A_BAD_ARG"); return; }
    bool clamped = setTargetDegrees(motors[LEFT], values[0]);
    // Een enkele waarde betekent: beide wielen dezelfde hoek.
    clamped |= setTargetDegrees(motors[RIGHT], (count == 2) ? values[1] : values[0]);
    ackOk("A", clamped);
    return;
  }
  if (strcmp(cmd, "AL") == 0 || strcmp(cmd, "AR") == 0) {
    count = parseFloats(arg, values, 1);
    if (count != 1) { ackErr("A_BAD_ARG"); return; }
    bool clamped = setTargetDegrees(motors[cmd[1] == 'L' ? LEFT : RIGHT], values[0]);
    ackOk(cmd, clamped);
    return;
  }

  // ---- Relatieve verplaatsing (jog, voor kalibratie) --------------------
  if (strcmp(cmd, "J") == 0) {
    count = parseFloats(arg, values, 2);
    if (count == PARSE_ERROR || count == 0) { ackErr("J_BAD_ARG"); return; }
    float dl = values[0];
    float dr = (count == 2) ? values[1] : values[0];
    bool clamped = setTargetDegrees(motors[LEFT],  stepsToDegrees(motors[LEFT].targetSteps)  + dl);
    clamped     |= setTargetDegrees(motors[RIGHT], stepsToDegrees(motors[RIGHT].targetSteps) + dr);
    ackOk("J", clamped);
    return;
  }

  // ---- Vast / vrij zetten ----------------------------------------------
  if (strcmp(cmd, "E") == 0 || strcmp(cmd, "EL") == 0 || strcmp(cmd, "ER") == 0) {
    count = parseFloats(arg, values, 1);
    if (count != 1) { ackErr("E_BAD_ARG"); return; }
    bool on = (values[0] != 0.0f);
    if (strcmp(cmd, "E") == 0) {
      setEnabled(motors[LEFT],  on);
      setEnabled(motors[RIGHT], on);
    } else {
      setEnabled(motors[cmd[1] == 'L' ? LEFT : RIGHT], on);
    }
    ackOk(cmd);
    return;
  }

  // ---- Nulpunt instellen ------------------------------------------------
  if (strcmp(cmd, "Z")  == 0) { zeroMotor(motors[LEFT]); zeroMotor(motors[RIGHT]); ackOk("Z");  return; }
  if (strcmp(cmd, "ZL") == 0) { zeroMotor(motors[LEFT]);                           ackOk("ZL"); return; }
  if (strcmp(cmd, "ZR") == 0) { zeroMotor(motors[RIGHT]);                          ackOk("ZR"); return; }

  // ---- Uitlezen ---------------------------------------------------------
  if (strcmp(cmd, "P") == 0) { printPositions(); return; }
  if (strcmp(cmd, "S") == 0) { printStatus();    return; }
  if (strcmp(cmd, "I") == 0) { Serial.println("ID:OPENAGBOT-STEER,2.0,MOTORS=2"); return; }

  // ---- Snelheid en acceleratieramp --------------------------------------
  if (strcmp(cmd, "V") == 0) {
    count = parseFloats(arg, values, 3);
    if (count == PARSE_ERROR || count == 0) { ackErr("V_BAD_ARG"); return; }
    if (values[0] < 20.0f || values[0] > 100000.0f) { ackErr("V_OUT_OF_RANGE"); return; }
    minStepDelayUs = (unsigned long)values[0];
    if (count >= 2) {
      if (values[1] < (float)minStepDelayUs) { ackErr("V_START_BELOW_MIN"); return; }
      startStepDelayUs = (unsigned long)values[1];
    }
    if (count >= 3) {
      if (values[2] < 0.0f) { ackErr("V_RAMP_NEGATIVE"); return; }
      rampSteps = (long)values[2];
    }
    if (startStepDelayUs < minStepDelayUs) startStepDelayUs = minStepDelayUs;
    ackOk("V");
    return;
  }

  // ---- Softwarelimiet op de stuuruitslag --------------------------------
  if (strcmp(cmd, "M") == 0) {
    count = parseFloats(arg, values, 1);
    if (count != 1) { ackErr("M_BAD_ARG"); return; }
    if (values[0] <= 0.0f || values[0] > 180.0f) { ackErr("M_OUT_OF_RANGE"); return; }
    maxAngleDeg = values[0];
    // Bestaande doelen opnieuw begrenzen, anders blijft een oud doel buiten de limiet staan.
    for (uint8_t i = 0; i < MOTOR_COUNT; i++) {
      setTargetDegrees(motors[i], stepsToDegrees(motors[i].targetSteps));
    }
    ackOk("M");
    return;
  }

  ackErr("UNKNOWN_CMD");
}

// ---------------------------------------------------------------------------
// Seriele invoer: niet-blokkerend regel voor regel inlezen.
// (readStringUntil() zou tot de timeout blijven hangen en de motoren stilzetten.)
// ---------------------------------------------------------------------------
void handleSerial() {
  while (Serial.available() > 0) {
    char c = (char)Serial.read();

    if (c == '\r') continue;

    if (c == '\n') {
      if (lineOverflow) {
        ackErr("LINE_TOO_LONG");
      } else if (lineLen > 0) {
        lineBuf[lineLen] = '\0';
        processCommand(lineBuf);
      }
      lineLen      = 0;
      lineOverflow = false;
      return; // een commando per loop-iteratie, zodat de motoren blijven lopen
    }

    if (lineLen < sizeof(lineBuf) - 1) {
      lineBuf[lineLen++] = c;
    } else {
      lineOverflow = true;
    }
  }
}

// ---------------------------------------------------------------------------
void setup() {
  // Zelfde baudrate als de Jetson setup en als de DAC-Arduino. Op de R4 Minima
  // is Serial native USB CDC, dus dit getal wordt door de hardware genegeerd;
  // het staat er voor de consistentie en voor als je ooit naar Serial1 (D0/D1)
  // overstapt, waar het wel een echte UART-snelheid is.
  // Niet wachten op een host: de robot moet ook zonder laptop kunnen opstarten.
  Serial.begin(115200);

  for (uint8_t i = 0; i < MOTOR_COUNT; i++) {
    pinMode(motors[i].pulPin, OUTPUT);
    pinMode(motors[i].dirPin, OUTPUT);
    pinMode(motors[i].enaPin, OUTPUT);
    digitalWrite(motors[i].pulPin, LOW);
    digitalWrite(motors[i].dirPin, LOW);
    motors[i].lastDir        = 0;
    motors[i].lastStepMicros = micros();
    setEnabled(motors[i], true); // start met beide wielen vast op hun huidige stand
  }

  Serial.println("READY");
}

void loop() {
  handleSerial();  // luister naar de Jetson
  serviceMotors(); // stap beide motoren richting hun doelhoek
}

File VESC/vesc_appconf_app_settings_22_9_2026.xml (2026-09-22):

<?xml version="1.0" encoding="UTF-8"?>
<APPConfiguration>
    <ConfigVersion>4</ConfigVersion>
    <controller_id>1</controller_id>
    <timeout_msec>1000</timeout_msec>
    <timeout_brake_current>0</timeout_brake_current>
    <can_status_rate_1>50</can_status_rate_1>
    <can_status_rate_2>5</can_status_rate_2>
    <can_status_msgs_r1>1</can_status_msgs_r1>
    <can_status_msgs_r2>30</can_status_msgs_r2>
    <can_baud_rate>2</can_baud_rate>
    <pairing_done>0</pairing_done>
    <permanent_uart_enabled>1</permanent_uart_enabled>
    <shutdown_mode>7</shutdown_mode>
    <can_mode>0</can_mode>
    <uavcan_esc_index>0</uavcan_esc_index>
    <uavcan_raw_mode>0</uavcan_raw_mode>
    <uavcan_raw_rpm_max>50000</uavcan_raw_rpm_max>
    <uavcan_status_current_mode>0</uavcan_status_current_mode>
    <servo_out_enable>0</servo_out_enable>
    <kill_sw_mode>0</kill_sw_mode>
    <app_to_use>0</app_to_use>
    <app_ppm_conf.ctrl_type>0</app_ppm_conf.ctrl_type>
    <app_ppm_conf.pid_max_erpm>15000</app_ppm_conf.pid_max_erpm>
    <app_ppm_conf.hyst>0.15</app_ppm_conf.hyst>
    <app_ppm_conf.pulse_start>1</app_ppm_conf.pulse_start>
    <app_ppm_conf.pulse_end>2</app_ppm_conf.pulse_end>
    <app_ppm_conf.pulse_center>1.5</app_ppm_conf.pulse_center>
    <app_ppm_conf.median_filter>1</app_ppm_conf.median_filter>
    <app_ppm_conf.safe_start>1</app_ppm_conf.safe_start>
    <app_ppm_conf.throttle_exp>0</app_ppm_conf.throttle_exp>
    <app_ppm_conf.throttle_exp_brake>0</app_ppm_conf.throttle_exp_brake>
    <app_ppm_conf.throttle_exp_mode>2</app_ppm_conf.throttle_exp_mode>
    <app_ppm_conf.ramp_time_pos>0.4</app_ppm_conf.ramp_time_pos>
    <app_ppm_conf.ramp_time_neg>0.2</app_ppm_conf.ramp_time_neg>
    <app_ppm_conf.multi_esc>1</app_ppm_conf.multi_esc>
    <app_ppm_conf.tc>0</app_ppm_conf.tc>
    <app_ppm_conf.tc_max_diff>3000</app_ppm_conf.tc_max_diff>
    <app_ppm_conf.max_erpm_for_dir>4000</app_ppm_conf.max_erpm_for_dir>
    <app_ppm_conf.smart_rev_max_duty>0.07</app_ppm_conf.smart_rev_max_duty>
    <app_ppm_conf.smart_rev_ramp_time>3</app_ppm_conf.smart_rev_ramp_time>
    <app_adc_conf.ctrl_type>0</app_adc_conf.ctrl_type>
    <app_adc_conf.hyst>0.15</app_adc_conf.hyst>
    <app_adc_conf.voltage_start>0.9</app_adc_conf.voltage_start>
    <app_adc_conf.voltage_end>3</app_adc_conf.voltage_end>
    <app_adc_conf.voltage_min>0</app_adc_conf.voltage_min>
    <app_adc_conf.voltage_max>3.5</app_adc_conf.voltage_max>
    <app_adc_conf.voltage_center>2</app_adc_conf.voltage_center>
    <app_adc_conf.voltage2_start>0.9</app_adc_conf.voltage2_start>
    <app_adc_conf.voltage2_end>3</app_adc_conf.voltage2_end>
    <app_adc_conf.use_filter>1</app_adc_conf.use_filter>
    <app_adc_conf.safe_start>1</app_adc_conf.safe_start>
    <app_adc_conf.buttons>0</app_adc_conf.buttons>
    <app_adc_conf.voltage_inverted>0</app_adc_conf.voltage_inverted>
    <app_adc_conf.voltage2_inverted>0</app_adc_conf.voltage2_inverted>
    <app_adc_conf.throttle_exp>0</app_adc_conf.throttle_exp>
    <app_adc_conf.throttle_exp_brake>0</app_adc_conf.throttle_exp_brake>
    <app_adc_conf.throttle_exp_mode>2</app_adc_conf.throttle_exp_mode>
    <app_adc_conf.ramp_time_pos>0.3</app_adc_conf.ramp_time_pos>
    <app_adc_conf.ramp_time_neg>0.1</app_adc_conf.ramp_time_neg>
    <app_adc_conf.multi_esc>1</app_adc_conf.multi_esc>
    <app_adc_conf.tc>0</app_adc_conf.tc>
    <app_adc_conf.tc_max_diff>3000</app_adc_conf.tc_max_diff>
    <app_adc_conf.update_rate_hz>500</app_adc_conf.update_rate_hz>
    <app_uart_baudrate>115200</app_uart_baudrate>
    <app_chuk_conf.ctrl_type>0</app_chuk_conf.ctrl_type>
    <app_chuk_conf.hyst>0.15</app_chuk_conf.hyst>
    <app_chuk_conf.ramp_time_pos>0.4</app_chuk_conf.ramp_time_pos>
    <app_chuk_conf.ramp_time_neg>0.2</app_chuk_conf.ramp_time_neg>
    <app_chuk_conf.stick_erpm_per_s_in_cc>3000</app_chuk_conf.stick_erpm_per_s_in_cc>
    <app_chuk_conf.throttle_exp>0</app_chuk_conf.throttle_exp>
    <app_chuk_conf.throttle_exp_brake>0</app_chuk_conf.throttle_exp_brake>
    <app_chuk_conf.throttle_exp_mode>2</app_chuk_conf.throttle_exp_mode>
    <app_chuk_conf.multi_esc>1</app_chuk_conf.multi_esc>
    <app_chuk_conf.tc>0</app_chuk_conf.tc>
    <app_chuk_conf.tc_max_diff>3000</app_chuk_conf.tc_max_diff>
    <app_chuk_conf.use_smart_rev>1</app_chuk_conf.use_smart_rev>
    <app_chuk_conf.smart_rev_max_duty>0.07</app_chuk_conf.smart_rev_max_duty>
    <app_chuk_conf.smart_rev_ramp_time>3</app_chuk_conf.smart_rev_ramp_time>
    <app_chuk_conf.coast_brake_level>0</app_chuk_conf.coast_brake_level>
    <app_chuk_conf.coast_brake_ramp_time>1</app_chuk_conf.coast_brake_ramp_time>
    <app_nrf_conf.speed>1</app_nrf_conf.speed>
    <app_nrf_conf.power>3</app_nrf_conf.power>
    <app_nrf_conf.crc_type>1</app_nrf_conf.crc_type>
    <app_nrf_conf.retry_delay>0</app_nrf_conf.retry_delay>
    <app_nrf_conf.retries>3</app_nrf_conf.retries>
    <app_nrf_conf.channel>76</app_nrf_conf.channel>
    <app_nrf_conf.address__0>198</app_nrf_conf.address__0>
    <app_nrf_conf.address__1>199</app_nrf_conf.address__1>
    <app_nrf_conf.address__2>0</app_nrf_conf.address__2>
    <app_nrf_conf.send_crc_ack>1</app_nrf_conf.send_crc_ack>
    <app_pas_conf.ctrl_type>0</app_pas_conf.ctrl_type>
    <app_pas_conf.sensor_type>0</app_pas_conf.sensor_type>
    <app_pas_conf.pedal_rpm_start>10</app_pas_conf.pedal_rpm_start>
    <app_pas_conf.pedal_rpm_end>180</app_pas_conf.pedal_rpm_end>
    <app_pas_conf.invert_pedal_direction>0</app_pas_conf.invert_pedal_direction>
    <app_pas_conf.magnets>24</app_pas_conf.magnets>
    <app_pas_conf.use_filter>1</app_pas_conf.use_filter>
    <app_pas_conf.current_scaling>0.1</app_pas_conf.current_scaling>
    <app_pas_conf.ramp_time_pos>0.6</app_pas_conf.ramp_time_pos>
    <app_pas_conf.ramp_time_neg>0.3</app_pas_conf.ramp_time_neg>
    <app_pas_conf.update_rate_hz>500</app_pas_conf.update_rate_hz>
    <imu_conf.type>1</imu_conf.type>
    <imu_conf.mode>0</imu_conf.mode>
    <imu_conf.filter>1</imu_conf.filter>
    <imu_conf.accel_lowpass_filter_x>0</imu_conf.accel_lowpass_filter_x>
    <imu_conf.accel_lowpass_filter_y>0</imu_conf.accel_lowpass_filter_y>
    <imu_conf.accel_lowpass_filter_z>0</imu_conf.accel_lowpass_filter_z>
    <imu_conf.gyro_lowpass_filter>0</imu_conf.gyro_lowpass_filter>
    <imu_conf.sample_rate_hz>200</imu_conf.sample_rate_hz>
    <imu_conf.use_magnetometer>1</imu_conf.use_magnetometer>
    <imu_conf.accel_confidence_decay>1</imu_conf.accel_confidence_decay>
    <imu_conf.mahony_kp>0.3</imu_conf.mahony_kp>
    <imu_conf.mahony_ki>0</imu_conf.mahony_ki>
    <imu_conf.madgwick_beta>0.1</imu_conf.madgwick_beta>
    <imu_conf.rot_roll>0</imu_conf.rot_roll>
    <imu_conf.rot_pitch>0</imu_conf.rot_pitch>
    <imu_conf.rot_yaw>0</imu_conf.rot_yaw>
    <imu_conf.accel_offsets__0>0</imu_conf.accel_offsets__0>
    <imu_conf.accel_offsets__1>0</imu_conf.accel_offsets__1>
    <imu_conf.accel_offsets__2>0</imu_conf.accel_offsets__2>
    <imu_conf.gyro_offsets__0>0</imu_conf.gyro_offsets__0>
    <imu_conf.gyro_offsets__1>0</imu_conf.gyro_offsets__1>
    <imu_conf.gyro_offsets__2>0</imu_conf.gyro_offsets__2>
</APPConfiguration>

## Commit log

2026-05-14 Heading + caddesigns
    [Bruut_OpenAgbot.scad, Bruut_OpenAgbot_3D_printable.scad, axle_bracket.scad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]
2026-05-20 Create throttle_map_20260515_215910_low.csv
    Add throttle map data for low speed settings.
    [throttle_map_20260515_215910_low.csv]
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2026-05-20 Increase side plate dimensions
    [parameters.scad]
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2026-05-23 chassis_frame_asm conflict fixes
    [chassis_frame_asm.scad, main_assembly.scad, main_base_plate.scad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]
2026-05-24 synched grid pattern 40mm
    [chassis_beam.scad, chassis_beam_1.scad, chassis_beam_2.scad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]
2026-05-24 fixed main_assaembly
    [chassis_beam_construct_asm.scad, main_assembly.scad]
2026-05-24 adding casterwheels and 2wd assembly
    [caster_wheel_asm.scad, caster_wheel_axle.scad, caster_wheel_beam.scad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]
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2026-05-25 Update notes.txt with STL file import instructions
    Added instructions for placing STL files and sources for models.
2026-05-25 Refactor Navigator for 10Hz Heading Fusion and Tolerance
    Updated Navigator class for improved heading fusion and waypoint tolerance.
2026-05-25 Update axle dimensions for bracket configuration
    [parameters.scad]
2026-05-27 Implement DXF export option for axle bracket
    Add conditional export for 2D DXF representation.
    [axle_bracket.scad]
2026-05-27 DXF export function
    Added conditional export for DXF format and updated bracket_side_plate module parameters.
    [bracket_side_plate.scad]
2026-05-27 Implement DXF export option for bracket top plate
    Added conditional export for DXF or 3D rendering of the bracket top plate.
    [bracket_top_plate.scad]
2026-06-05 push met de logica van 3axis sturen
    [steppermotor_information.json]
2026-06-12 thichness from 5 to 4 mm
    [parameters.scad]
2026-06-12 Increase template width from 80 to 100
    [axle_bracket_drill_template.scad]
2026-06-14 fixed AB_navigation code still sucks
    [Extract_route_data.py]
2026-06-15 Vervang waypoint-gebaseerde kopakker-bocht door vaste-boog met heading-feedback
    De oude implementatie volgde een lijst gegenereerde waypoints via pure pursuit,
    wat kon resulteren in eindeloze cirkels als een punt gemist werd. De nieuwe
    aanpak rijdt een constante stuurhoek (vaste draaicirkel) en sluit de bocht
    zodra de koers binnen tolerantie van de volgende baanrichting ligt, met een
    veiligheidstimeout als backup. Verwijdert turn_wp_threshold_m en
    turn_waypoints/turn_wp_index; voegt turn_heading_tol_deg, turn_timeout_s en
    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
2026-06-15 grid to 50 mm ipv 40mm veelvoud
    [chassis_beam_1.scad, chassis_beam_2.scad, chassis_beam_construct_asm.scad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]
2026-06-18 Document UVC camera integration on NVIDIA Jetson
    Added detailed information about UVC cameras on NVIDIA Jetson, including integration, compatibility, and performance evaluation.
2026-07-30 centrum holes in bracket top plate
    [bracket_top_plate.scad, parameters.scad]
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2026-08-09 Add bolt diameter universal
    Added bolt diameter parameters for M12, M10, and M8 bolts.
    [parameters.scad]
2026-08-09 Update minimum chassis width parameter
    [parameters.scad]
2026-08-09 Refactor drill template for modular design
    [chassis_beam_drill_template.scad]
2026-08-10 extra speling toegevoegd
    [chassis_beam_drill_template.scad]
2026-08-11 Clarify axle diameter specification in parameters
    Updated axle diameter comment for clarity.
    [parameters.scad]
2026-08-11 template distance side brackets
    [distance_brackets_template.scad, distance_brackets_template.stl]
2026-08-11 sacrifice rings for beam drill template
    [axle_bracket_drill_template.stl, chassis_beam_drill_template.scad, chassis_beam_drill_template_bushing.stl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]
2026-08-12 Increase tpl_tongue_extra from 4 to 8
    [distance_brackets_template.scad]
2026-08-16 Add bracket top plate holes template
    This file contains a template for drilling holes in a top plate, with options for different views and configurations.
    [bracket_top_plate_holes_template.scad]
2026-08-18 templates centrum top bracket plates
    [bracket_top_plate_holes_template.scad, bracket_top_plate_holes_template_centrum.stl, bracket_top_plate_pipe_center_template.scad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]
2026-08-19 Update tpl_gap_reach for base plate cutout adjustment
    Increased the tpl_gap_reach value to adjust the cutout radius in the base plate.
    [bracket_top_plate_pipe_center_template.scad]
2026-08-19 templates for PX86 reducer
    [drill_bushing_m6.scad, drill_bushing_m6.stl, parameters.scad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]
2026-08-22 2 frontwheels steering
    [steppermotor_information.json]
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2026-09-16 Add disclaimer for experimental prototype usage
    Added a disclaimer about the experimental nature and risks of the prototype.
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2026-09-17 Update README_can.md with connection warning
    Clarified warning about connecting Pin 1 to 5V on the VESC to prevent damage.
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2026-09-21 Add SCAD file for Daheng camera mount design
    [va_imaging_camera_mount.scad]
2026-09-21 rendered 21-9-2026
    rendered 21-9-2026 , for newer .scad changes render it again and update is
    [va_imaging_camera_mount.stl]
2026-09-21 Modify camera mount design and update plate module
    [va_imaging_camera_mount.scad]
2026-09-21 rendered 21-9-2026
    rendered 21-9-2026
    [va_imaging_camera_mount.stl]
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2026-09-22 New VESC config Files
    [vesc_appconf_app_settings_22_9_2026.xml, vesc_mcconf_motor_settings_22_9_2026.xml]
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2026-09-25 camera fixes, rotation
2026-09-25 MAX Amps upped and V cutt off lowered
    [vesc_mcconf_motor_settings_22_9_2026.xml]
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2026-10-04 add freecad designs
    [Bruut_OpenAgbot.FCStd, PLOATIE 2.STP]
